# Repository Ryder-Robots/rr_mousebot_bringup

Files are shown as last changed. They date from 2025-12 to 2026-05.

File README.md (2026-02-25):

# RR Mousebot Bringup

ROS 2 launch package for an autonomous maze-solving robot designed to comply with IEEE Micromouse competition specifications.

## Project Overview

This package provides the core system bringup for a micromouse-compliant robot. While the robot does not compete in official competitions, it is designed to meet the technical specifications established by IEEE Micromouse competition rules for educational and developmental purposes.

The micromouse competition, first introduced by IEEE Spectrum in 1977, challenges participants to design and build autonomous robots capable of navigating from a start position to the center of an unknown maze in the shortest time possible (Christiansen, 1977). This project implements a ROS 2-based system that adheres to these specifications.

### IEEE Micromouse Competition Specifications

The robot is designed to comply with standard IEEE Micromouse specifications:

**Maze Specifications:**
- 16 x 16 grid of unit squares (each 18cm x 18cm)
- Wall height: 5 cm
- Wall thickness: 1.2 cm (±5% tolerance)
- Passageway width: 16.8 cm
- Total maze size: approximately 8 feet (2.44m) square
- Wall colors: white sides with red tops
- Floor: non-gloss black painted wood
(Micromouse Online, n.d.; IEEE Region 2, 2018)

**Robot Design Requirements:**
- Maximum dimensions: 25cm x 25cm (no height restriction)
- Must be self-contained (no remote control or external assistance)
- Cannot use combustion-based energy sources
- Must be fully autonomous
- Superstructure may extend above maze walls
(Micromouse Online, n.d.)

**Competition Rules (for reference):**
- 10-minute time limit for maze exploration and solving
- No ROM changes or program downloads after maze is revealed
- Each exit from starting square begins a new run
- Must reach destination square (center) for time to be recorded
- No communication with robot during competition runs
(IEEE Spectrum, 1979)

## Architecture

The `rr_mousebot.launch.py` launch file initializes a composable node container and a delayed lifecycle manager.

### Driver Container (`driver_container`)

Runs as `component_container_mt` (multi-threaded) under the `/driver` namespace.

**Active nodes:**

- **Motor Controller** (`rr_motor_controller::RrECU`, plugin: `rr_motor_controller::RrECU`):
  Lifecycle node (`nav2_util::LifecycleNode`) providing dual-motor PWM drive, quadrature encoder odometry, and odometry publishing.
  - GPIO transport: `rr_gpio_pi4b_pigpio_plugin::RrGpioPi4BPigpioPlugin` (Raspberry Pi 4B)
  - Encoder pins: `[9, 8]` (left, right); PWM pins: `[18, 19]`; Direction pins: `[23, 24]`
  - Wheel radius: 20 mm; wheel base: 70 mm; PPR: 8; PWM frequency: 1000 Hz
  - Encoder timeout: 500 000 µs
  - `use_intra_process_comms: True`

**Pending nodes (commented out, awaiting integration):**

- **UDP Receiver/Sender** (`udp_driver`): Network telemetry and debugging transport

### Lifecycle Manager

`nav2_lifecycle_manager` is launched with a **3-second `TimerAction` delay** to allow the driver container and its composable nodes to fully initialise before the manager attempts to discover them.

- `autostart: False` — lifecycle transitions are triggered manually (for debugging)
- `bond_timeout: 4.0 s` — heartbeat monitoring active once nodes reach the `active` state
- Manages: `/driver/motor_controller`

**Pending managed nodes (commented out):** `lidar_node`, `/driver/serial_bridge_node`, `/driver/udp_receiver_node`, `/driver/udp_sender_node`, `/sensor/rr_imu_action_node`

## Lifecycle Management Approach

The system employs ROS 2 lifecycle nodes to manage operational modes and optimize power consumption during different phases of maze solving:

### Operational Phases

1. **Explore Mode** (LIDAR Active)
   - System maps the 16x16 maze grid using 360° LIDAR
   - All sensors active for SLAM and navigation
   - Typical duration: 10-15 minutes
   - Power consumption: 3.7A (battery usage ~7-10%)
   - Returns to home position after complete exploration

2. **Planning Phase** (LIDAR Inactive)
   - LIDAR lifecycle transitioned to INACTIVE state to conserve power
   - Computes optimal path to center using A* or similar algorithm
   - Minimal power consumption during computation

3. **Run Mode** (LIDAR Inactive)
   - Executes pre-computed optimal path at maximum speed
   - LIDAR remains INACTIVE via lifecycle management
   - Power consumption: 3.4A (300mA savings per run)
   - Typical run duration: 30-60 seconds
   - Battery usage per run: ~0.3-0.6%

### Lifecycle Benefits

- **Power Efficiency**: Disabling LIDAR during runs saves ~300mA, enabling 150-175 runs per battery charge after initial exploration
- **Competition Ready**: Single battery supports 5-7 full competition attempts (explore + multiple runs) within 10-minute time limit
- **Resource Management**: Systematic activation/deactivation of sensor nodes based on operational requirements

## Battery Testing

Battery test results show the batteries are rated at 3.8V on charge, drawing approximately 3A during operation.

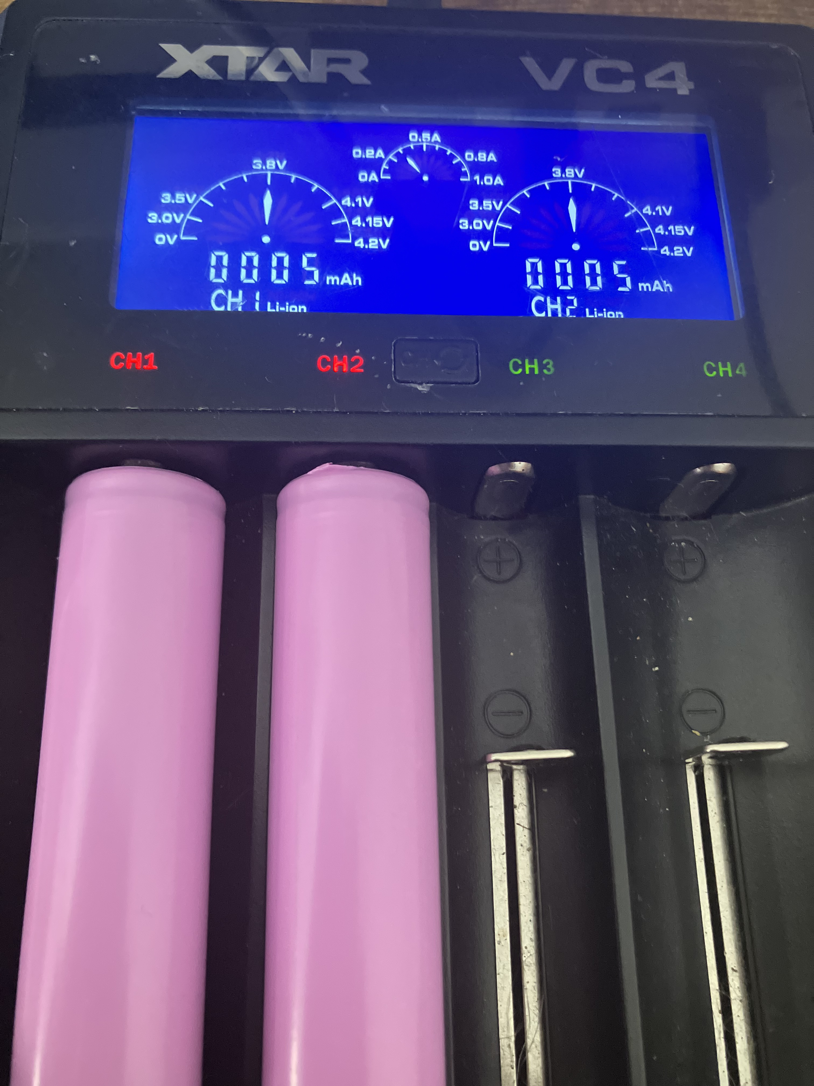
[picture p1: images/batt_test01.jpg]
Battery Test


## Schematic Directory

The [schematic/](schematic/) directory contains FreeCAD design files (.FCStd) for all mechanical and electrical components of the micromouse robot. These 3D CAD models are used for prototyping, assembly planning, and dimensional verification to ensure compliance with IEEE Micromouse specifications.

Key component designs include:
- Robot chassis and body assemblies
- Motor and encoder mountings
- Wheel designs (drive and caster wheels)
- Electronics mounting (Raspberry Pi, Arduino Nano, power circuits)
- Battery pack housing
- Power management circuits (buck converters)

The `stl/` subdirectory will be populated with STL files in future versions for 3D printing of custom components.

For detailed information about individual components, see [schematic/README.md](schematic/README.md).

For 3D printing instructions and assembly guidance, see [CONSTRUCTION.md](CONSTRUCTION.md).

## Dependencies and Installation

### ROS 2 System Requirements

This package requires ROS 2 and several dependency packages. Install the following components in order:

### Third-Party Dependencies

1. **Transport Drivers** (serial/UDP communication)
   ```bash
   # Install from https://github.com/ros-drivers/transport_drivers
   ```

2. **NAV2** (SLAM and navigation - under review)
   - Documentation: https://docs.nav2.org/tutorials/docs/navigation2_with_slam.html
   ```bash
   sudo apt install ros-${ROS_DISTRO}-nav2-bringup
   ```

3. **LD200 LIDAR Driver** (ldrobot-lidar-ros2)
   ```bash
   # Install dependencies
   sudo apt install libudev-dev

   # Clone into your ROS 2 workspace
   cd ~/ros2_ws/src
   git clone https://github.com/Myzhar/ldrobot-lidar-ros2.git

   # Apply ROS 2 Kilted patch (REQUIRED)
   cd ldrobot-lidar-ros2
   patch -p1 < ../rr_mousebot_bringup/scripts/ldrobot-lidar-ros2-kilted.patch

   # Build the package
   cd ~/ros2_ws
   rosdep install --from-paths src --ignore-src -r -y
   colcon build --symlink-install --cmake-args=-DCMAKE_BUILD_TYPE=Release --packages-select ldlidar ldlidar_component ldlidar_node
   ```
   - Native ROS 2 Lifecycle node with NAV2 lifecycle_manager integration
   - Driver for LD14P LIDAR sensor (part of D200 Developer Kit) - use `model: 'LDLiDAR_LD19'`
   - Device: `/dev/ttyAMA0` (Raspberry Pi hardware UART)
   - Topic: `/ldlidar_node/scan`
   - Patch file: [scripts/ldrobot-lidar-ros2-kilted.patch](scripts/ldrobot-lidar-ros2-kilted.patch)
   - See [CONSTRUCTION.md](CONSTRUCTION.md) for detailed setup and lifecycle management

### Ryder Robots Core Packages

Install the following Ryder Robots packages in order:

1. **Interfaces** (message/service definitions)
   ```bash
   # Clone and build: https://github.com/Ryder-Robots/rr_interfaces
   ```

2. **Common Base** (shared utilities and base classes)
   ```bash
   # Clone and build: https://github.com/Ryder-Robots/rr_common_base
   ```

3. **Common Plugins** (lifecycle and plugin components)
   ```bash
   # Clone and build: https://github.com/Ryder-Robots/rr_common_plugins
   ```

4. **Proto** (communication layer between Arduino and ROS 2)
   ```bash
   # Clone and build: https://github.com/Ryder-Robots/rr_proto
   ```

5. **Actions** (action server implementations)
   ```bash
   # Clone and build: https://github.com/Ryder-Robots/rr_imu_action
   # Note: Will be renamed to rr_actions and include all action implementations
   ```

### Optional Development Tools

- **Joystick Support** (recommended for testing and manual control)
  ```bash
  # Clone and build: https://github.com/Ryder-Robots/rr_joystick
  ```

### Arduino Firmware

Flash the Arduino Nano 33 BLE Sense Rev2 with the micromouse firmware:
- Repository: https://github.com/Ryder-Robots/rr_ble33_mousebot

### ROS 2 Installation

```bash
sudo apt update
sudo apt install ros-${ROS_DISTRO}-launch ros-${ROS_DISTRO}-launch-ros

# Source your ROS 2 workspace
source /opt/ros/${ROS_DISTRO}/setup.bash
source install/setup.bash
```

## Launch Command

```bash
ros2 launch rr_mousebot_bringup rr_mousebot.launch.py
```

## Manually configuring nodes

With `autostart: False`, the lifecycle manager starts but does not transition any nodes automatically. Use the service call or direct lifecycle commands:

```bash
# Trigger full startup (configure + activate all managed nodes) via lifecycle manager:
ros2 service call /lifecycle_manager_navigation/manage_nodes \
  nav2_msgs/srv/ManageLifecycleNodes "{command: 0}"

# Or drive the motor controller directly, one step at a time:
ros2 lifecycle get /driver/motor_controller
# unconfigured [1]
ros2 lifecycle set /driver/motor_controller configure
# Transitioning successful
ros2 lifecycle set /driver/motor_controller activate
# Transitioning successful
```

## Developer Notes

### Repository Architecture

This repository (`rr_mousebot_bringup`) contains all **mazebot-specific** components and configuration. All other repositories used by this project are designed to be **generic and reusable** across different robotic platforms and applications.

**Mazebot-Specific (this repository):**
- Launch configurations for the micromouse robot
- Hardware-specific parameter files
- Mazebot system integration and bringup logic
- Bill of Materials (BOM) and construction documentation
- Mechanical design files and schematics

**Generic/Reusable Repositories:**
- `rr_interfaces`: Common ROS 2 message and service definitions
- `rr_common_base`: Base lifecycle node implementations
- `rr_common_plugins`: Pluginlib-based navigation and control plugins
- `rr_proto`: Protocol buffer definitions for serial communication
- `rr_imu_action`: IMU-based action server implementations (being refactored to `rr_actions`)
- `rr_joystick`: Joystick/gamepad input handling
- `transport_drivers`: Serial and UDP communication drivers

These generic repositories can be used in other robotic projects, providing a modular foundation for ROS 2-based systems. Only `rr_mousebot_bringup` ties these components together into the specific mazebot application.

## References

Christiansen, D. (1977) 'The Amazing Micromouse Contest', *IEEE Spectrum*, 14(5). Available at: https://spectrum.ieee.org/the-amazing-micromouse-contest (Accessed: 13 December 2025).

IEEE Region 2 (2018) *Micromouse Competition Rules - IEEE R2 SAC 2018*. Available at: https://ewh.ieee.org/reg/2/sac-18/MicromouseRules.pdf (Accessed: 13 December 2025).

IEEE Spectrum (1979) 'The Amazing Micromouse Maze Contest', *IEEE Spectrum*, 16(6). Available at: https://spectrum.ieee.org/the-amazing-micromouse-contest (Accessed: 13 December 2025).

Micromouse Online (n.d.) *The Rules - Micromouse Book*. Available at: https://micromouseonline.com/micromouse-book/rules/ (Accessed: 13 December 2025).

Micromouse Online (n.d.) *Chassis Size - Micromouse Book*. Available at: https://micromouseonline.com/micromouse-book/the-chassis/chassis-size/ (Accessed: 13 December 2025).

## License

This project is licensed under the MIT License.

Copyright (c) 2025

Permission is hereby granted, free of charge, to any person obtaining a copy of this software and associated documentation files (the "Software"), to deal in the Software without restriction, including without limitation the rights to use, copy, modify, merge, publish, distribute, sublicense, and/or sell copies of the Software, and to permit persons to whom the Software is furnished to do so, subject to the following conditions:

The above copyright notice and this permission notice shall be included in all copies or substantial portions of the Software.

THE SOFTWARE IS PROVIDED "AS IS", WITHOUT WARRANTY OF ANY KIND, EXPRESS OR IMPLIED, INCLUDING BUT NOT LIMITED TO THE WARRANTIES OF MERCHANTABILITY, FITNESS FOR A PARTICULAR PURPOSE AND NONINFRINGEMENT. IN NO EVENT SHALL THE AUTHORS OR COPYRIGHT HOLDERS BE LIABLE FOR ANY CLAIM, DAMAGES OR OTHER LIABILITY, WHETHER IN AN ACTION OF CONTRACT, TORT OR OTHERWISE, ARISING FROM, OUT OF OR IN CONNECTION WITH THE SOFTWARE OR THE USE OR OTHER DEALINGS IN THE SOFTWARE.

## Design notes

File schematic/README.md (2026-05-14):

# Schematic Directory

This directory contains FreeCAD (.FCStd) design files for all mechanical and electrical components of the RR Mousebot. These 3D CAD models are used for design verification, assembly planning, and ensuring compliance with IEEE Micromouse competition specifications (maximum footprint: 25cm x 25cm).

## Directory Structure

```
schematic/
├── README.md           # This file
├── stl/                # STL and 3MF files for 3D printing
│   ├── body.stl        # Main chassis STL file
│   ├── body.3mf        # Main chassis 3MF file (recommended)
│   ├── drive_shaft.stl # Drive shaft STL file
│   └── drive_shaft.3mf # Drive shaft 3MF file (recommended)
└── *.FCStd             # FreeCAD design files
```

## STL Files

The `stl/` subdirectory contains 3D printable files exported from the FreeCAD designs. Files are provided in both STL and 3MF formats:

- **3MF Format** (recommended): Preserves units, scale, and metadata. Use with Elegoo Slicer for best results.
- **STL Format**: Universal format compatible with all slicers.

**Available Components:**
- `body.stl` / `body.3mf`: Main robot chassis (40% infill recommended)
- `drive_shaft.stl` / `drive_shaft.3mf`: Motor drive shaft (100% infill required for strength)

For detailed printing instructions, slicer settings, and post-processing guidance, see [CONSTRUCTION.md](../CONSTRUCTION.md).

## Component Design Files

### Main Assembly Files

#### [mazebot.FCStd](mazebot.FCStd)
Complete robot assembly integrating all mechanical and electrical components. This is the master assembly file that shows how all individual components fit together to form the complete micromouse robot.

#### [body.FCStd](body.FCStd)
Main chassis/body design for the robot. This component houses all electronics, motors, sensors, and power systems while maintaining compliance with the 25cm x 25cm maximum footprint requirement.

### Drive System Components

#### [hexwheel.FCStd](hexwheel.FCStd)
Hexagonal wheel design for the main drive wheels. The hex pattern may provide improved traction and maze navigation characteristics compared to standard circular wheels.

#### [caster_wheel.FCStd](caster_wheel.FCStd)
Caster wheel assembly providing passive support and stability. Typically mounted at the front or rear of the robot to create a stable three or four-point contact with the maze floor.

#### [tt_motor.FCStd](tt_motor.FCStd)
TT (Toy Train) motor model used for robot propulsion. These compact DC gear motors are commonly used in small robotics applications due to their favorable size-to-power ratio.

#### [motor_encoder.FCStd](motor_encoder.FCStd)
Optical encoder assembly for motor shaft position and velocity feedback. Encoders are essential for accurate odometry and closed-loop motor control during maze navigation.

### Electronics Mounting

#### [Raspberry Pi 4 Model B.STEP.FCStd](Raspberry%20Pi%204%20Model%20B.STEP.FCStd)
Raspberry Pi 4 Model B mounting design. The Pi serves as the main compute platform running ROS 2 and high-level navigation algorithms.

#### [nano-breakout.FCStd](nano-breakout.FCStd)
Arduino Nano breakout board design for interfacing with sensors and motor controllers. The Nano handles real-time sensor reading and motor control, communicating with the Raspberry Pi via serial connection.

#### [pi-rough.FCStd](pi-rough.FCStd)
Rough/preliminary mounting design for Raspberry Pi. This may be an earlier iteration or alternative mounting configuration for the Pi board.

### Power System

#### [battery_pack.FCStd](battery_pack.FCStd)
Battery pack housing and mounting design. Proper battery placement is critical for maintaining the robot's center of gravity and ensuring stable maze navigation.

#### [buck_circuit.FCStd](buck_circuit.FCStd)
Buck converter circuit mounting for power regulation. Buck converters step down the battery voltage to appropriate levels for different components (e.g., 5V for Raspberry Pi, 3.3V for sensors, motor voltage regulation).

## Bill of Materials (BOM)

This section lists the commercial off-the-shelf (COTS) components required to build the RR Mousebot. Prices are in AUD and include GST unless otherwise noted.

### Computing and Control

| Component | SKU | Quantity | Unit Price (inc GST) | Supplier | Notes |
|---|-----|---|---|---|---|
| Raspberry Pi 4 Model B 8GB | CE06974 | 1 | $145.00 | [Core Electronics](https://core-electronics.com.au/raspberry-pi-4-model-b-8gb.html) | Main compute platform for ROS 2 and navigation algorithms. 1.5GHz quad-core ARM Cortex-A72, Gigabit Ethernet, dual-band WiFi, Bluetooth 5.0. Typical current: ~3A at 5V |
| IO Expansion HAT for Raspberry Pi 4B/3B+ | DFR0566 | 1 | $17.50 | [Core Electronics](https://core-electronics.com.au/io-expansion-hat-for-raspberry-pi-4b-3b.html) | DFRobot GPIO expansion HAT. Provides UART, I²C, SPI, PWM, and digital I/O breakout terminals. 65×56mm. D200 LIDAR connects to UART terminals (T/R/5V/GND). Compatible with Gravity Series sensors |

### Sensors

| Component | SKU | Quantity | Unit Price (inc GST) | Supplier | Notes |
|---|-----|---|---|---|---|
| 360° Omni-directional Triangulation Lidar Dev Kit (8m range) | WS-24659 | 1 | $94.10 | [Core Electronics](https://core-electronics.com.au/360-omni-directional-triangulation-lidar-dev-kit-8m-range.html) | D200 Developer Kit with LD14P Lidar. 8m range, ±1.5% accuracy, 360° scanning, 4000Hz ranging frequency, UART @ 230400 baud (/dev/ttyAMA0 on Pi 4B/Pi 5). 5V DC, ≤300mA operating current. Includes UART to USB adapter. ROS 2 driver: https://github.com/Myzhar/ldrobot-lidar-ros2 (native lifecycle node, use model `LDLiDAR_LD19` for D200/LD14P). For SLAM, mapping, and obstacle detection |
| Adafruit BNO055 Absolute Orientation Sensor | CE04489 | 1 | $65.95 | [Core Electronics](https://core-electronics.com.au/adafruit-9-dof-absolute-orientation-imu-fusion-breakout-bno055.html) | Bosch BNO055 9-axis IMU. Provides fused absolute orientation (quaternion, Euler angles), angular velocity, and linear acceleration. I²C interface, address 0x28 (default) on /dev/i2c-1. 3.3V logic compatible. Onboard sensor fusion handles magnetometer calibration. Connects to DFR0566 HAT I²C terminals. ROS 2 driver: rr_bosch_lc_base |

### Motor Control

| Component | SKU | Quantity | Unit Price (inc GST) | Supplier | Notes |
|---|-----|---|---|---|---|
| Micro DC Geared Motor w/ Encoder - SJ01 6V 160RPM 120:1 | FIT0450 | 2 | $13.20 | [Core Electronics](https://core-electronics.com.au/micro-dc-geared-motor-w-encoder-sj01-6v-160rpm-120-1.html) | DFRobot micro DC motor with integrated Hall effect encoder. 120:1 gear ratio, 160 RPM @ 6V, stall torque 0.8 kg.cm. Operating voltage: 3-6V DC, no-load current 45mA, stall current 350mA. Encoder: 16 PPR (pulses per revolution of motor shaft), 1920 counts per revolution at output shaft (16 PPR × 120 gear ratio). Compact design: 25mm length (including output shaft). Includes pre-soldered 6-pin connector. Wiki: https://wiki.dfrobot.com/Micro_DC_Motor_with_Encoder-SJ01_SKU__FIT0450 |
| Makerverse Motor Driver 2 Channel | CE08038 | 1 | $7.20 | [Core Electronics](https://core-electronics.com.au/makerverse-motor-driver-2-channel.html) | Dual H-bridge motor driver. 1.6A continuous (2A peak), 3-16V input, compatible with 3.3V/5V logic. Includes thermal protection, reverse-polarity protection, and 5V regulator. 35x30mm with M3 mounting holes |

### Electrical Interface

| Component | SKU | Quantity | Unit Price (inc GST) | Supplier | Notes |
|---|-----|---|---|---|---|
| Logic Level Converter - Bidirectional | BOB-12009 | 1 | $2.95 | [Core Electronics](https://core-electronics.com.au/logic-level-converter-bidirectional.html) | SparkFun bidirectional 4-channel logic level converter. Shifts signals between 3.3V (Pi GPIO) and 5V (LIDAR, motor driver). Used in GPIO-controlled LIDAR power switch circuit |
| MOSFET Power Switch Module | CE09733 | 1 | $1.35 | [Core Electronics](https://core-electronics.com.au/mosfet-power-switch-module.html) | GPIO-controlled MOSFET power switch. **GPIO 24** controls 5V rail to LIDAR, held low during boot to prevent UART flooding on /dev/ttyAMA0. Software-controlled power-on in LIDAR node on_activate |

### Power System

| Component | SKU | Quantity | Unit Price (inc GST) | Supplier | Notes |
|---|-----|---|---|---|---|
| Samsung 18650 3500mAh 3.7V Rechargeable Battery | SB2632 | 2 | $33.50 | [Jaycar](https://www.jaycar.com.au/18650-samsung-3500mah-3-7v-18650-rechargeable-battery/p/SB2632) | Samsung INR18650-35E. 3500mAh capacity, 3.5A continuous/10A peak discharge. 7.4V nominal (2S configuration), 7000mAh total capacity provides ~51.8Wh energy storage |
| Dual 18650 Battery Holder | PH9207 | 1 | $6.95 | [Jaycar](https://www.jaycar.com.au/dual-18650-battery-holder/p/PH9207) | ABS plastic holder with 150mm leads. 75x39x20mm. Suitable for 2S (series) configuration providing 7.4V nominal output |
| DC-DC Adjustable Step-down Module 5A 75W | CE07271 | 1 | $2.55 | [Core Electronics](https://core-electronics.com.au/dc-dc-adjustable-step-down-module-5a-75w.html) | XL4015 buck converter. Input: 4-38V, Output: 1.25-36V adjustable, 5A max. 30-turn potentiometers for voltage/current adjustment. Provides 5V rail for Raspberry Pi and Lidar. Arduino Nano powered via USB from Raspberry Pi. 54x24x12mm with 3mm mounting holes |

### Mechanical Components

| Component | SKU | Quantity | Unit Price (inc GST) | Supplier | Notes |
|---|-----|---|---|---|---|
| Wheel - 65mm (Rubber Tire, Pair) | ROB-13259 | 1 | $9.55 | [Core Electronics](https://core-electronics.com.au/wheel-65mm-rubber-tire-pair.html) | Sparkfun basic wheels with black rubber tires. 65mm diameter, sold as pair (2 wheels). Compatible with DAGU right angle gear motors. For main drive wheels on differential drive robot |
| Supporting Swivel Caster Wheel - 1.3" Diameter | ADA2942 | 1 | $5.75 | [Core Electronics](https://core-electronics.com.au/supporting-swivel-caster-wheel-1-3-diameter.html) | 360° rotating support wheel. 32.4mm diameter, 42mm total height. Provides third-point stability for robot |
| Brass Heat-Set Inserts for Plastic - M3 x 3mm - 50 pack | ADA4256 | 1 | $11.65 | [Core Electronics](https://core-electronics.com.au/brass-heat-set-inserts-for-plastic-m3-x-3mm-50-pack.html) | M3 threaded brass inserts for 3D printed parts. 4.5mm OD, 3mm length. Heat-press installation with soldering iron. Provides strong, reusable threaded mounting points in plastic chassis |
| Makerverse M3 Mounting Kit | CE08342 | 1 | $3.25 | [Core Electronics](https://core-electronics.com.au/makerverse-m3-mounting-kit.html) | Hardware kit with 4x M3x12mm standoffs and 8x 6mm screws. For mounting electronics to chassis (up to 3mm material thickness) |

### BOM Notes

- **Total Component Cost** (listed items only): ~$422 AUD (excludes battery charger and 3D printed parts)

- **Power System Summary**: 2S Li-ion configuration (2x 18650 cells in series)
  - Nominal voltage: 7.4V (fresh), ~5.5V (under load/partially discharged)
  - Total capacity: 7000mAh (51.8Wh)
  - Continuous discharge: 7A (3.5A per cell)
  - Peak discharge: 20A (10A per cell, 5 seconds)
  - **Buck Converter Configuration** (adjust using flathead screwdriver):
    - Single converter: 5.5V → 5.0V rail for Raspberry Pi, LIDAR, and BNO055 (3.0A continuous load)
    - BNO055 IMU: Powered via DFR0566 HAT I²C rail (3.3V, included in Pi's power budget)
  - Motor power: Battery voltage (7.4V nominal, 5.5V under load) direct from battery through motor driver

- **Battery Charging**:
  - **IMPORTANT**: Battery cells must be removed from the holder and charged using an external 18650 Li-ion battery charger
  - Compatible chargers available from Core Electronics and Jaycar Australia
  - Do NOT attempt to charge batteries while installed in the robot
  - Recommended: 2S (7.4V) Li-ion smart charger with balance charging capability

- **Total Current Load Analysis** (at 5.5V battery voltage under load):
  - **5V Rail** (via Buck Converter):
    - Raspberry Pi 4: 3.0A (typical under load)
    - BNO055 IMU: ~0.01A (via DFR0566 HAT, included in Pi's budget)
    - LD14P Lidar: 0.3A (300mA operating current)
    - Motor Driver Control: 0.01A (minimal)
    - **Subtotal 5V Rail**: 3.36A (buck converter rated 5A, 67% utilization)
  - **Direct Battery (5.5V-7.4V)**:
    - Micro DC Motors with Encoders: 0.09A no-load (2x 45mA), 0.7A stall (2x 350mA max)
    - Typical operation (partial load): ~0.2A
    - **Subtotal Direct**: 0.2A typical
  - **System Total**: ~3.56A from battery typical (7A continuous capacity, 51% utilization)
  - **Runtime Estimate (Full System Active)**: 7000mAh / 3560mA ≈ 2.0 hours continuous operation

- **Operational Mode Battery Life Analysis**:
  - **Full System Runtime**:
    - Current draw: 3.56A typical (all systems active including LIDAR)
    - Runtime: 7000mAh / 3560mA ≈ **2.0 hours** (120 minutes) continuous operation
  - **Competition Scenario** (10-minute time limit):
    - Exploration phase: 10-15 minutes @ 3.56A = 593-890mAh (8-13% battery)
    - Speed runs with LIDAR inactive: @ 3.26A, minimal battery usage per run
    - **Result**: 5-7 full competition attempts (explore + multiple runs) per full battery charge
    - 360° LIDAR provides comprehensive SLAM and mapping with 8m range and ±1.5% accuracy

- **Motor System Summary**: 2x Micro DC Geared Motors with integrated Hall effect encoders for differential drive
  - Operating voltage: 3-6V DC (6V nominal, 5.5V typical under load)
  - Current draw: 45mA per motor no-load, ~100mA typical partial load, 350mA stall (per motor)
  - Speed: 160 RPM @ 6V (estimated ~145-160 RPM @ 5.5V under load)
  - Encoder: 16 PPR (motor shaft), 1920 counts per revolution at output shaft (16 PPR × 120:1 gear ratio)
  - Gear ratio: 120:1
  - Stall torque: 0.8 kg.cm
  - Motor driver provides 1.6A continuous capacity (>2x safety margin for typical operation, handles stall current)

- **Assembly Notes**:
  - Buck converter requires tuning with flathead screwdriver to achieve precise 5.0V output
  - Use multimeter to verify output voltage before connecting to Raspberry Pi
  - BNO055 IMU connects to DFR0566 HAT I²C terminals (SDA/SCL/3.3V/GND). Default I²C address: 0x28
  - Brass heat-set inserts (ADA4256) provide threaded mounting points in 3D printed chassis for M3 screws

- **Additional Components Required** (not listed above):
  - 18650 Li-ion battery charger (2S/7.4V compatible) - available from Core Electronics or Jaycar
  - Wiring, connectors, and miscellaneous hardware
  - 3D printed structural components (chassis, motor mounts, sensor brackets)
  - M3 screws (various lengths) for use with heat-set inserts

- **Quantity Discounts**: Available for most components when ordering 6+ or 10+ units
- **Availability**: Most items ship same business day; Lidar has lead time (ships Jan 6-9, 2025)
- **Suppliers**: Components sourced from Core Electronics Australia and Jaycar Australia

### Component Selection Rationale

- **Raspberry Pi 4 8GB**: Provides adequate computational power for ROS 2 nodes, SLAM algorithms, and path planning. 8GB RAM ensures headroom for development and debugging. 3A typical current draw fits within 5A buck converter capacity
- **BNO055 IMU**: Dedicated 9-axis orientation sensor with onboard sensor fusion. Provides quaternion output and linear acceleration directly — no fusion computation on the Pi. I²C interface integrates cleanly with the DFR0566 HAT and is natively supported by rr_bosch_lc_base as a ROS 2 lifecycle component. Eliminates the Arduino layer, simplifying the stack and reducing latency on the IMU data path
- **360° LIDAR (LD14P)**: 8m range exceeds maze dimensions (~2.5m), ±1.5% accuracy suitable for 18cm grid navigation. 360° scanning at 4000Hz ranging frequency enables comprehensive SLAM and obstacle detection. UART interface @ 230400 baud on /dev/ttyAMA0 (Raspberry Pi hardware UART, compatible with both Pi 4B and Pi 5). Low power consumption (≤300mA) with native ROS 2 Lifecycle node support via ldrobot-lidar-ros2 driver (https://github.com/Myzhar/ldrobot-lidar-ros2) - use `model: 'LDLiDAR_LD19'` for D200/LD14P sensor. Includes D200 developer kit with UART to USB adapter
- **Micro DC Geared Motors with Encoders (FIT0450)**: Ultra-compact design (25mm length) fits within tight micromouse footprint. 120:1 gear ratio provides excellent balance between speed (160 RPM @ 6V) and torque (0.8 kg.cm stall) for maze navigation. Integrated Hall effect encoder (16 PPR motor shaft = 1920 counts/rev at output shaft) eliminates need for separate encoder modules. Low power consumption: 45mA no-load, ~100mA typical operation. Pre-soldered 6-pin connector simplifies wiring. Comprehensive documentation: https://wiki.dfrobot.com/Micro_DC_Motor_with_Encoder-SJ01_SKU__FIT0450
- **Motor Driver**: 1.6A continuous current rating provides adequate safety margin (>8x for typical 200mA operation, >2x for 700mA stall current). Dual H-bridge enables independent bidirectional control for differential drive. Built-in 5V regulator, thermal protection, and compact form factor (35x30mm) with M3 mounting holes
- **Battery System**: Samsung 18650 cells chosen for high energy density (3500mAh), reliable performance, and proven track record. 2S configuration (7.4V nominal) provides appropriate voltage for motor driver input (3-16V range) and buck converter regulation. 51.8Wh total capacity supports ~2.0 hours continuous operation
- **Buck Converter**: Single XL4015 module provides reliable 5V regulation with 5A capacity exceeding system requirements (3.36A 5V rail + ~0.2A motors = 3.56A total load). Adjustable output voltage via 30-turn potentiometer enables precise 5.0V tuning with flathead screwdriver. Wide input range (4-38V) accommodates battery voltage variation during discharge. Arduino Nano powered via USB from Raspberry Pi eliminates need for separate 3.3V rail
- **Rubber Tire Wheels**: 65mm diameter wheels with black rubber tires provide good traction for differential drive robot. Sold as pair (2 wheels), compatible with DAGU right angle gear motors and suitable for micro DC motor mounting. Compact diameter fits within micromouse footprint constraints while providing adequate ground clearance
- **Heat-Set Inserts**: Brass M3 inserts provide strong, reusable threaded mounting points in 3D printed chassis. Superior to directly threading into plastic, allowing repeated assembly/disassembly without thread degradation. 50-pack provides sufficient quantity for entire robot assembly
- **Caster Wheel**: Small form factor (32.4mm) provides additional support point for stability during omnidirectional maneuvers
- **Mounting Hardware**: M3 standoffs provide secure mounting for motor driver and other electronics while maintaining proper spacing from chassis

## Electrical Circuits

### LIDAR Power Control — GPIO 24 via P-Channel MOSFET + NPN Inverter

The MOSFET Power Switch Module (CE09733) uses a **P-channel MOSFET**, which is active LOW on the SIG pin (SIG LOW = output ON, SIG HIGH = output OFF). Without an inverter, the floating GPIO at boot would leave SIG pulled low by default, powering the LIDAR immediately and flooding `/dev/ttyAMA0` before the ROS 2 driver is ready.

An NPN transistor inverter with a pull-up resistor solves this: the pull-up holds SIG HIGH at boot (LIDAR OFF), and driving GPIO 24 HIGH turns the NPN on, pulling SIG LOW (LIDAR ON).

**Logic table:**

| GPIO 24 | NPN | MOSFET SIG | LIDAR |
|---|-----|---|---|
| Float / LOW (boot) | OFF | HIGH (pull-up) | OFF ✅ |
| HIGH (software) | ON | LOW (pulled to GND) | ON ✅ |
| LOW (software) | OFF | HIGH (pull-up) | OFF ✅ |

**Components required:**

| Component | Value | Notes |
| --- | --- | --- |
| R1 | 1kΩ | Base resistor, GPIO 24 → NPN base |
| R2 | 10kΩ | Pull-up, 3.3V → MOSFET SIG |
| Q1 | NPN transistor | 2N2222, BC547, BC548, or S8050 |

**ASCII Schematic:**

```text
3.3V ─────────────────────────────────┐
                                      │
                                     R2
                                    10kΩ
                                      │
                                      ├──────────── MOSFET SIG
                                      │
Pi GPIO 24 ──── R1 ──── B            │
               1kΩ      │  Q1 (NPN)  │
                        C ───────────┘
                        E
                        │
GND ────────────────────┴──────────────────────────

MOSFET Power Switch Module (CE09733):
                                      
  5V Buck ──── [VIN │ P-CH MOSFET │ VOUT] ──── LIDAR 5V (red)
                    [     SIG     ]
                         │
                    (from NPN collector / R2 pull-up)

LIDAR GND ──── GND rail
LIDAR TX  ──── /dev/ttyAMA0 RX  (Pi GPIO 15)
LIDAR RX  ──── /dev/ttyAMA0 TX  (Pi GPIO 14)
```

**Physical wiring summary:**

```text
Pi header pin 18  (GPIO 24) ──── R1 (1kΩ) ──── Q1 base
Pi header pin 1   (3.3V)    ──── R2 (10kΩ) ─── Q1 collector ──── MOSFET SIG
Pi header pin 6   (GND)     ──── Q1 emitter
Buck 5V output              ──── MOSFET VIN
MOSFET VOUT                 ──── LIDAR 5V (red wire)
GND rail                    ──── LIDAR GND (black wire)
```

**Software control (lgpio):**

```python
import lgpio
h = lgpio.gpiochip_open(0)
lgpio.gpio_claim_output(h, 24)
lgpio.gpio_write(h, 24, 1)   # LIDAR ON
lgpio.gpio_write(h, 24, 0)   # LIDAR OFF
```

> **Note:** `gpiozero` on Ubuntu 24.04 requires `lgpio` as its backend. Install with `sudo apt install python3-lgpio`. Without it, GPIO commands succeed silently but produce no output.

---

## Design Workflow

1. **Individual Component Design**: Each mechanical and electrical component is designed in its own FreeCAD file with accurate dimensions and mounting features.

2. **Assembly Integration**: Components are imported and assembled in `mazebot.FCStd` to verify fit, clearances, and overall dimensions.

3. **Specification Verification**: The complete assembly is checked against IEEE Micromouse specifications:
   - Maximum footprint: 25cm x 25cm
   - Ground clearance compatible with 5cm maze walls
   - Center of gravity positioned for stable navigation

4. **STL Export** (future): Once designs are finalized, STL files will be exported to the `stl/` subdirectory for 3D printing.

## STL Subdirectory

The [stl/](stl/) subdirectory is reserved for STL (stereolithography) files that will be generated from the FreeCAD designs. These STL files will be:

- Optimized for 3D printing
- Properly oriented for minimal support material
- Scaled to actual dimensions
- Named to match their source FreeCAD files

**Status**: This directory will be populated in future versions as component designs are finalized and validated.

## Working with FreeCAD Files

To view or modify these designs:

1. Install FreeCAD (https://www.freecad.org/)
2. Open any `.FCStd` file in FreeCAD
3. Use the model tree to explore component features
4. Modify designs as needed for your specific hardware configuration

## Design Considerations

All component designs take into account:
- **IEEE Micromouse Compliance**: Maximum 25cm x 25cm footprint, no height restrictions
- **Maze Clearances**: 16.8cm passageway width, 5cm wall height
- **Component Integration**: Proper mounting points for electronics, sensors, and mechanical parts
- **Center of Gravity**: Low and centered for stable high-speed navigation
- **Serviceability**: Easy access to electronics and batteries for maintenance
- **Cable Routing**: Paths for power and data cables without interference

## File Naming Convention

- `*.FCStd`: FreeCAD native format files
- `*.STEP.FCStd`: FreeCAD files imported from STEP format (industry-standard CAD exchange format)
- `*.FCBak`: Automatic backup files created by FreeCAD (can be safely ignored)

## Version History

Component designs are version-controlled through Git. Refer to commit history for design evolution and changes. Major design iterations are documented in commit messages.

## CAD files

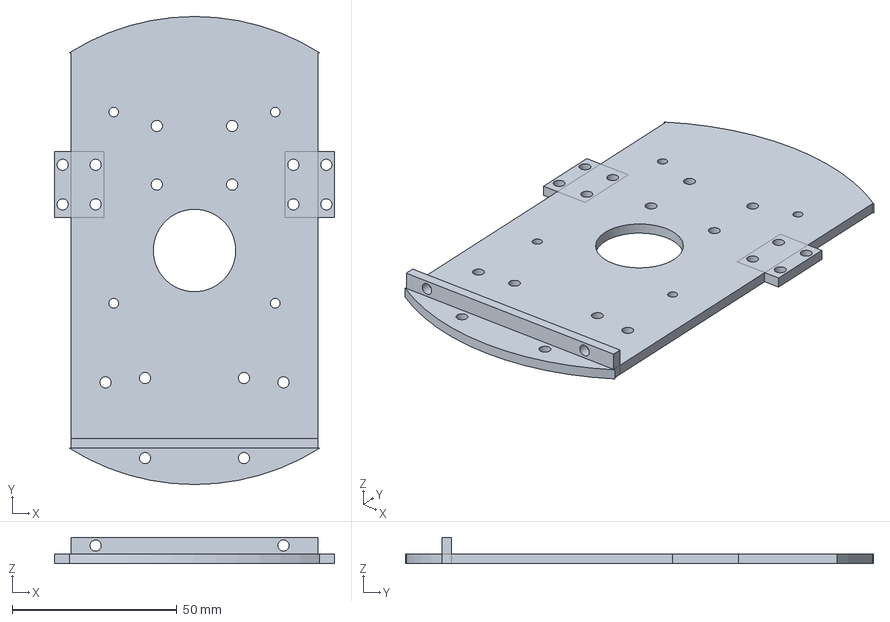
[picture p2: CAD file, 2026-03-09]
schematic/body.FCStd
85.0 x 142.0 x 8.00 mm

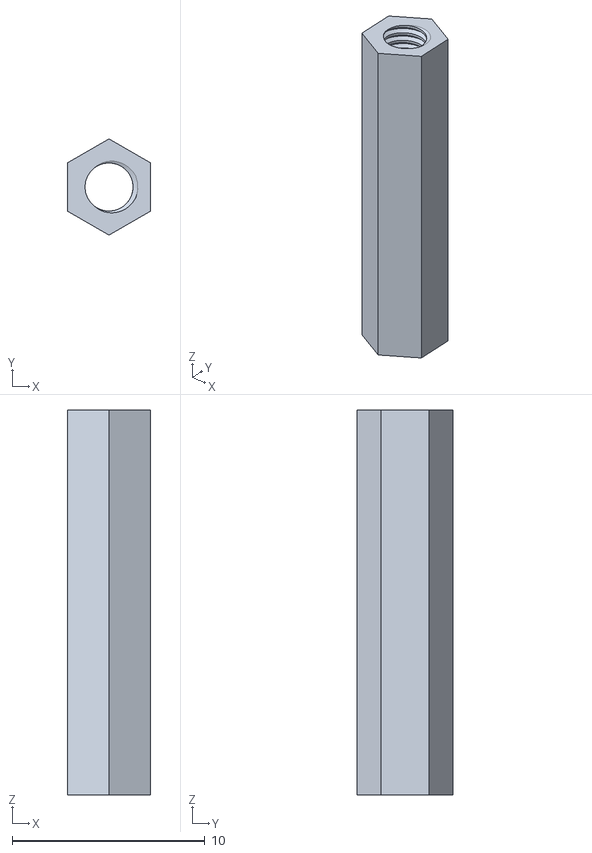
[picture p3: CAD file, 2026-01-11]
schematic/stl/m2.5_standoff.stl
4.33 x 5.00 x 20.0

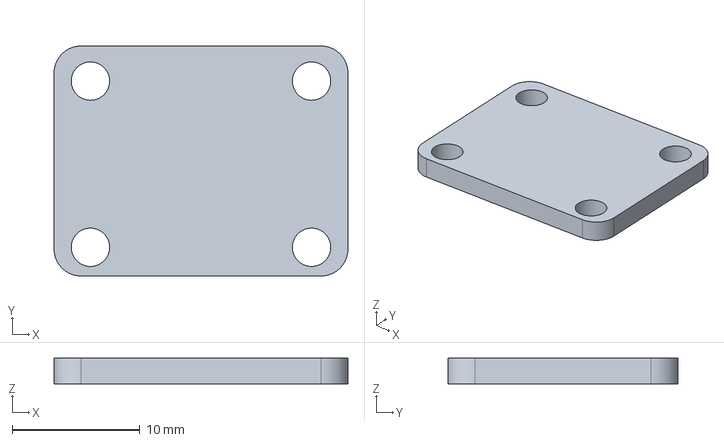
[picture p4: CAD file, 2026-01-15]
schematic/motor_encoder_bracket.FCStd
23.0 x 18.0 x 2.00 mm

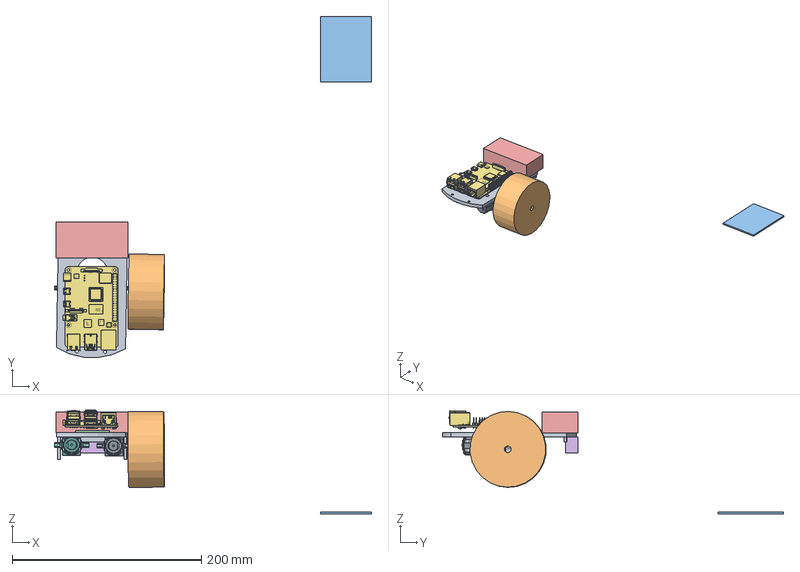
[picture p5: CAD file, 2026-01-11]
schematic/mazebot.FCStd
335.2 x 360.2 x 109.6 mm
body_Body_001
hexwheel_Body_002
nano-breakout_001
motor_encoder_001
battery_pack_001
buck_circuit_Body_001
Raspberry Pi 4 Model B.STEP_001
tt_motor_tt_motor001_001
tt_motor_tt_motor001_002

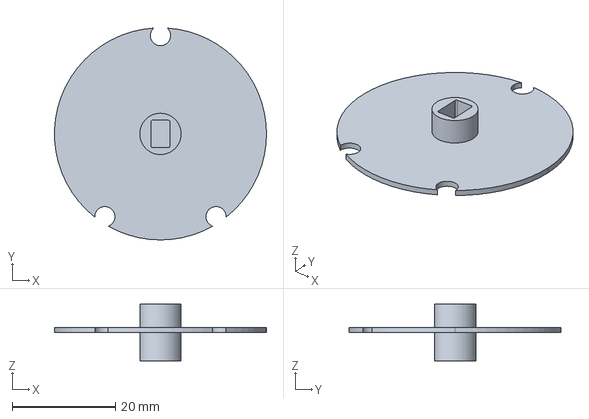
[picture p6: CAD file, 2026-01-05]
schematic/drive_shaft.FCStd
41.0 x 41.0 x 11.0 mm

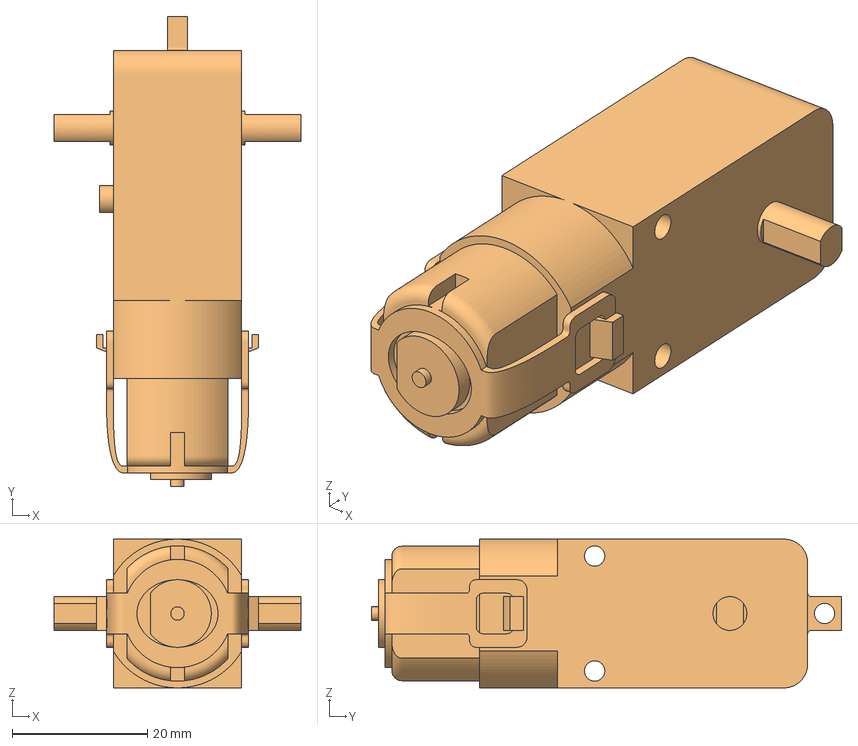
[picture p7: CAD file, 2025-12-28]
schematic/tt_motor.FCStd
36.5 x 69.5 x 22.0 mm
tt_motor001
tt_motor001 (Solid)
tt-motor

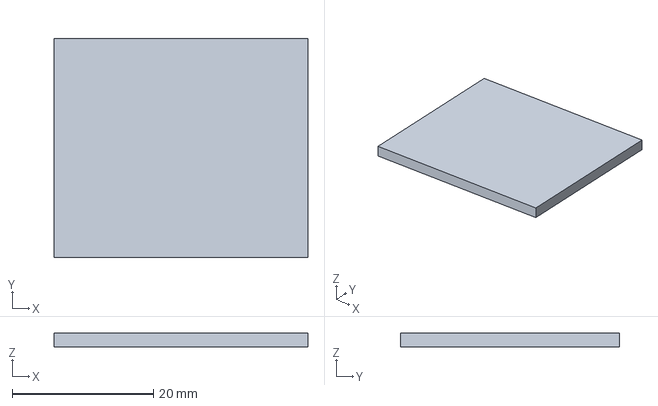
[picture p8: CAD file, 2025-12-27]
schematic/motor_encoder.FCStd
36.0 x 31.0 x 2.00 mm

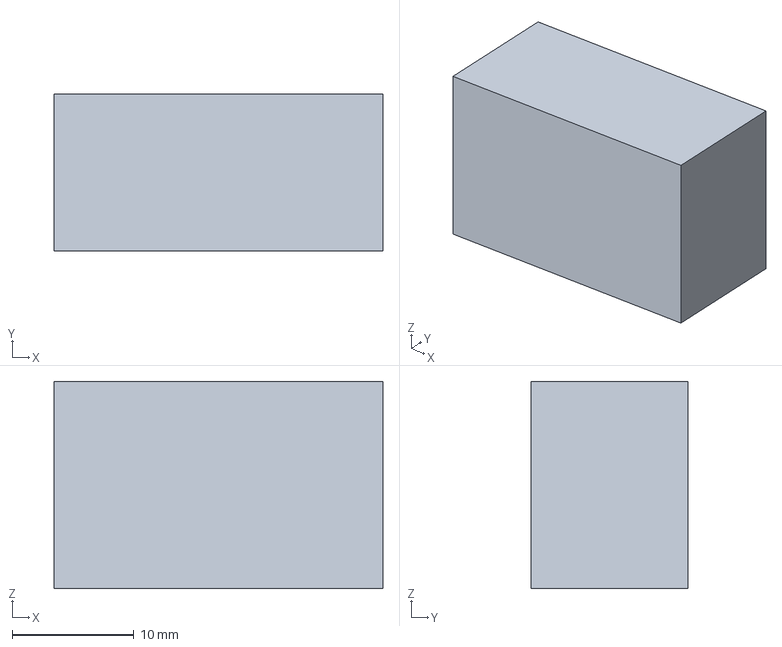
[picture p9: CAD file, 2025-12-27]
schematic/buck_circuit.FCStd
27.0 x 12.9 x 17.0 mm

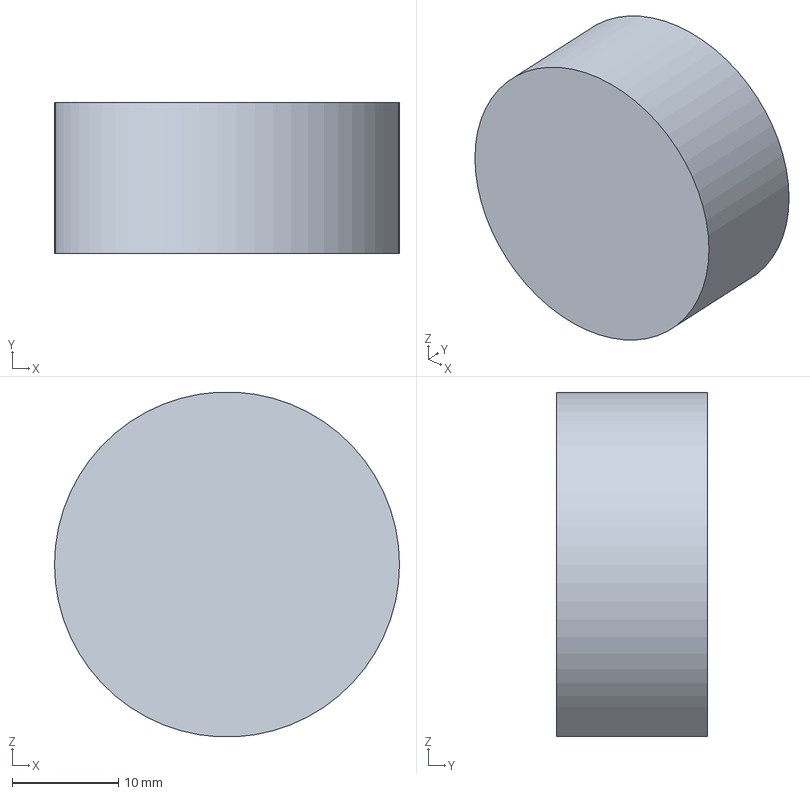
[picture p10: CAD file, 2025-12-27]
schematic/caster_wheel.FCStd
32.4 x 14.2 x 32.4 mm

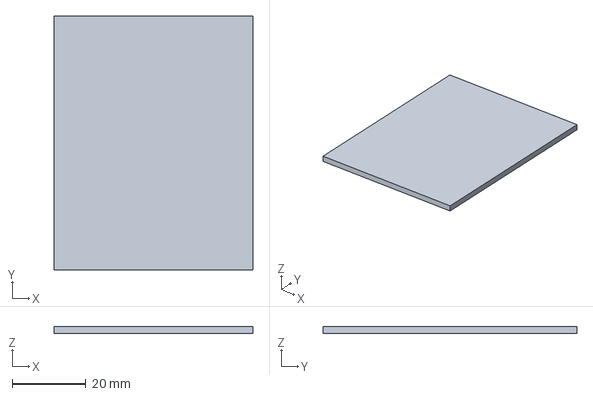
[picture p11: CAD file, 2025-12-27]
schematic/nano-breakout.FCStd
54.0 x 69.0 x 2.00 mm

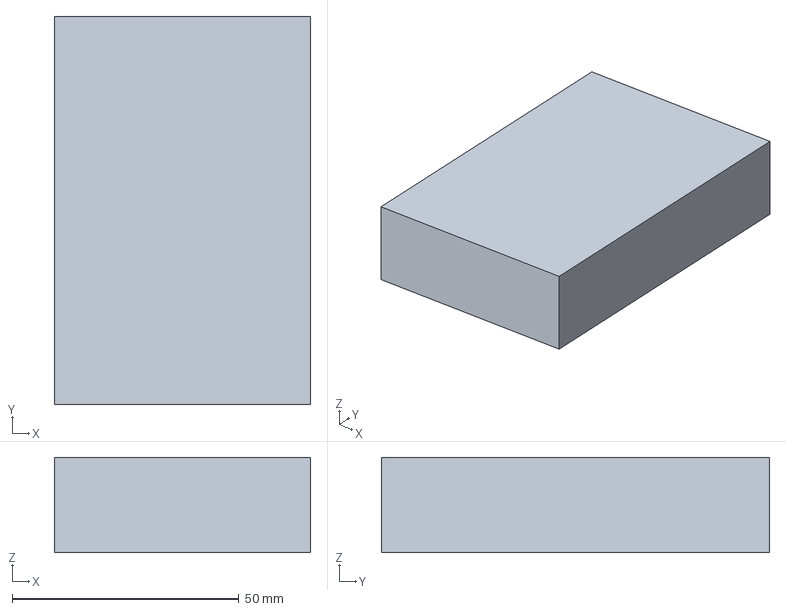
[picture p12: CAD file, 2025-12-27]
schematic/pi-rough.FCStd
56.5 x 85.6 x 21.0 mm

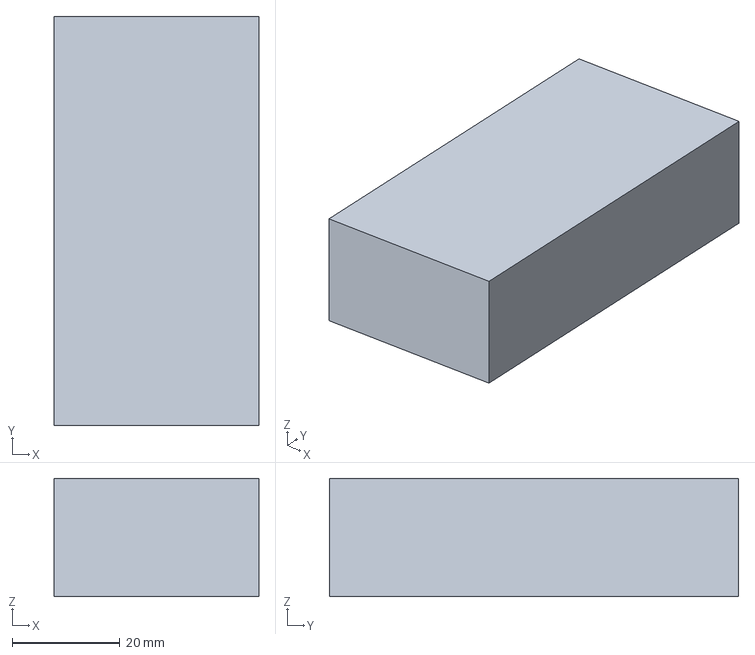
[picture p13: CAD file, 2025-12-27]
schematic/battery_pack.FCStd
38.0 x 76.0 x 22.0 mm

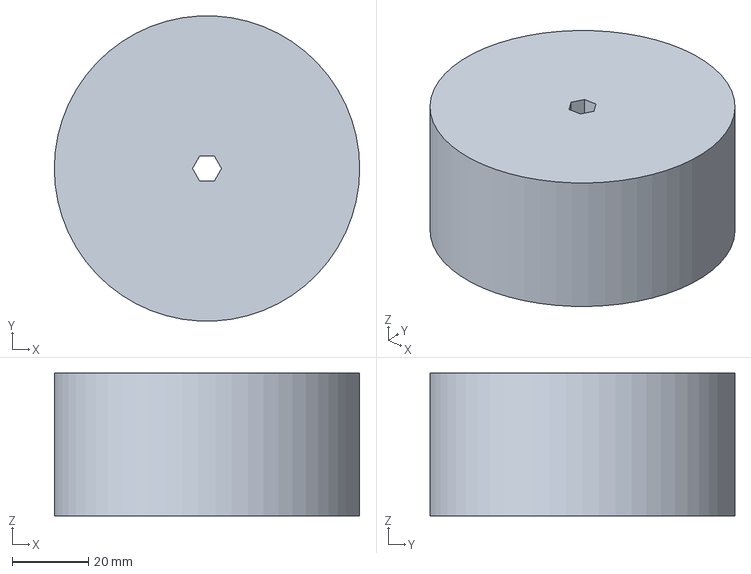
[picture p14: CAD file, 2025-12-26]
schematic/hexwheel.FCStd
80.0 x 79.9 x 37.4 mm

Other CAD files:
schematic/m2.5.FCStd
schematic/Raspberry Pi 4 Model B.STEP.FCStd
schematic/body.stl
schematic/stl/body.3mf
schematic/stl/body.stl
schematic/stl/motor_encoder_bracket.3mf
schematic/stl/motor_encoder_bracket.stl

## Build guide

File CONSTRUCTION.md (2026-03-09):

# RR Mousebot Construction Guide

This guide provides detailed instructions for 3D printing and assembling the RR Mousebot chassis and mechanical components.

## STL Files

All 3D printable files are located in the `schematic/stl/` directory. Files are provided in both STL and 3MF formats:

**Available Files:**

- `body.stl` / `body.3mf`: Main robot chassis
- `drive_shaft.stl` / `drive_shaft.3mf`: Motor drive shaft

**Format Recommendations:**

- **3MF Format** (recommended): Use with Elegoo Slicer for preserved scale, units, and metadata
- **STL Format**: Universal compatibility with any slicer software

See [schematic/README.md](schematic/README.md) for complete list of available components.

---

## 3D Printing Configuration

### Equipment

- **Printer**: Elegoo Centauri Carbon (enclosed)
- **Filament Dryer**: Creality Filament Heater
- **Recommended Slicer**: Elegoo Slicer (or compatible)

### Material Selection

- **Prototyping**: PETG (for quick iteration and testing)
- **Final Build**: ABS (for superior strength and durability)

This guide focuses on PETG settings for prototyping. ABS settings will be added for final production builds.

---

## PETG Printing Configuration

### Filament Preparation

PETG is hygroscopic and must be thoroughly dried before printing to prevent moisture-related defects (bubbles, stringing, weak layer adhesion).

#### Creality Filament Heater Settings

**Pre-Loading Drying (New or Exposed Filament)**:

- Temperature: 65-70°C
- Duration: 4-6 hours
- Purpose: Remove absorbed moisture before loading into printer

**Quick Dry (Recently Exposed Filament)**:

- Temperature: 60°C
- Duration: 2-4 hours
- Purpose: Light moisture removal without risking filament softening
- Note: Avoid higher temperatures to prevent PETG deformation

**Storage Mode (Active Storage)**:

- Temperature: 50-55°C
- Duration: Indefinite (while filament is loaded)
- Purpose: Maintain dry state during extended print sessions

**Best Practice**: Pre-dry at 65°C for 4-6 hours, then maintain at 50-55°C during printing.

---

### Elegoo Centauri Carbon Printer Settings

Configure these settings in your slicer (Elegoo Slicer recommended) for optimal PETG prints on the Centauri Carbon.

#### Temperature Settings

| Parameter | Temperature | Notes |
| --- | --- | --- |
| Nozzle (Standard) | 230-250°C | Start at 240°C for initial calibration |
| Nozzle (First Layer) | 245°C | Higher temp improves bed adhesion |
| Heated Bed | 70-80°C | Preheat for 10 minutes before printing |
| Chamber (with Creality mod) | 40-50°C | Enclosed chamber maintains stable temperature |

**Temperature Tuning**:

- If stringing occurs: Reduce nozzle temp by 5°C increments
- If layer adhesion is weak: Increase nozzle temp by 5°C increments
- If warping occurs: Increase bed temp to 80°C

#### Print Speed Settings

| Parameter | Speed | Notes |
| --- | --- | --- |
| First Layer | 20-30 mm/s | Slow for optimal bed adhesion |
| Perimeters | 30-40 mm/s | Balance quality and speed |
| Infill | 40-50 mm/s | Can be faster than perimeters |
| Travel Moves | 150-200 mm/s | Fast non-printing moves |
| Retraction Speed | 40 mm/s | Prevents stringing |

#### Cooling Settings

| Parameter | Setting | Notes |
| --- | --- | --- |
| Part Cooling Fan | 10-30% | PETG requires minimal cooling |
| First Layer Fan | 0% | No cooling for first layer adhesion |
| Bridging Fan | 40-50% | Increase for overhangs/bridges |

**Cooling Notes**:

- PETG is sensitive to over-cooling which causes warping and poor layer adhesion
- Use minimum cooling for structural parts
- Increase cooling slightly for detailed features or overhangs

#### Retraction Settings

| Parameter | Setting | Notes |
| --- | --- | --- |
| Retraction Distance | 0.5-1.0 mm | Start at 0.8mm for direct drive |
| Retraction Speed | 40 mm/s | Prevents nozzle clogging |
| Z-Hop on Retraction | 0.2 mm | Optional, reduces surface artifacts |

**Retraction Tuning**:

- Increase distance if stringing persists (up to 1.5mm max)
- Decrease if you observe clogging or under-extrusion after travels

#### Layer and Extrusion Settings

| Parameter | Setting | Notes |
| --- | --- | --- |
| Layer Height | 0.2 mm | Standard quality (0.12-0.28mm range) |
| First Layer Height | 0.2 mm | Match standard layer height |
| Line Width | 0.4 mm | Match nozzle diameter |
| Infill Density | 20-40% | 20% for prototypes, 40% for structural parts |
| Infill Pattern | Gyroid or Grid | Gyroid for strength, Grid for speed |
| Wall Count | 3-4 | Minimum 3 for strength |
| Top/Bottom Layers | 4-5 | Ensures solid surfaces |

#### Bed Adhesion

| Parameter | Setting | Notes |
| --- | --- | --- |
| Bed Surface | PEI Sheet or Glass with Glue Stick | Clean before each print |
| First Layer Flow | 105-110% | Slight over-extrusion for adhesion |
| Brim | Optional (5-10mm) | Use for small contact areas |
| Supports | Auto-generate | Enable for overhangs >50° |

**Bed Preparation**:

1. Clean PEI sheet with isopropyl alcohol before each print
2. For glass bed: Apply thin layer of glue stick or hairspray
3. Allow bed to preheat for 10 minutes to ensure even temperature distribution

---

### Elegoo Slicer Profile Template

Create a custom PETG profile in Elegoo Slicer with these settings:

```text
Filament: PETG
Nozzle: 240°C (first layer 245°C)
Bed: 75°C
Chamber: 45°C
Speed: 40 mm/s (first layer 25 mm/s)
Cooling: 20% (first layer 0%)
Retraction: 0.8mm @ 40mm/s
Layer Height: 0.2mm
Walls: 4
Infill: 30% Gyroid
Supports: Auto (>50° threshold)
```

---

## Print Quality Troubleshooting

### Common PETG Issues and Solutions

| Issue | Cause | Solution |
| --- | --- | --- |
| Stringing | Excessive moisture or temp too high | Dry filament at 65°C for 6 hours; reduce nozzle temp by 5°C |
| Warping | Insufficient bed temp or over-cooling | Increase bed temp to 80°C; reduce part cooling to 10% |
| Poor layer adhesion | Nozzle temp too low or wet filament | Increase nozzle temp to 245°C; dry filament thoroughly |
| Bubbling/Popping | Moisture in filament | Dry filament at 65-70°C for 6 hours minimum |
| Excessive stringing | Retraction settings incorrect | Increase retraction distance to 1.0mm; enable Z-hop 0.2mm |
| First layer not sticking | Bed not level or temp too low | Re-level bed; increase bed temp to 80°C; clean bed surface |

---

## Component-Specific Print Settings

### Chassis and Body Parts

**Files**: `body.stl` / `body.3mf`

**Priority**: Strength and durability

```text
Infill: 40% Gyroid
Walls: 4
Top/Bottom Layers: 5
Layer Height: 0.2mm
Supports: Yes (auto-generated)
```

### Motor Mounts and Brackets

**Priority**: High strength, heat resistance

```text
Infill: 50% Gyroid or Honeycomb
Walls: 5
Top/Bottom Layers: 6
Layer Height: 0.16mm (higher resolution)
Supports: Yes (manual placement recommended)
```

### Wheel Hubs and Drive Components

**Files**: `drive_shaft.stl` / `drive_shaft.3mf`

**Priority**: Maximum strength and precision

```text
Infill: 100% Solid
Walls: 4
Top/Bottom Layers: 5
Layer Height: 0.12mm (fine detail)
Supports: Minimal (design for printability)
```

**Note**: Drive shafts must be printed at 100% infill to withstand motor torque and prevent mechanical failure during operation.

### Electronic Enclosures

**Priority**: Fit tolerance and assembly ease

```text
Infill: 20% Grid (lightweight)
Walls: 3
Top/Bottom Layers: 4
Layer Height: 0.2mm
Supports: Minimal (use overhangs <45°)
```

---

## Heat-Set Insert Installation

After printing parts with heat-set insert holes:

1. **Preheat Soldering Iron**: 200-220°C for PETG
2. **Align Insert**: Position brass insert (M3 x 3mm) perpendicular to hole
3. **Apply Steady Pressure**: Press insert slowly and evenly until flush with surface
4. **Cool**: Allow part to cool for 2-3 minutes before removing iron
5. **Verify**: Test thread with M3 screw to ensure proper engagement

**Caution**: Do not exceed 250°C as PETG may deform around insert hole.

---

## Post-Processing

### Support Removal

- Remove support material carefully using flush cutters
- Sand contact points with 220-grit sandpaper for smooth finish
- Clean with compressed air to remove debris

### Surface Finishing (Optional)

- Light sanding with 400-grit sandpaper for smoother surfaces
- Acetone vapor smoothing NOT recommended for PETG (use for ABS only)
- **IMPORTANT**: Wear non-static gloves during sanding to prevent contaminants from adhering to components

### Component Washing

After support removal and sanding are complete, all printed components should be thoroughly cleaned:

1. **Wash Process**:
   - Use lukewarm water with a light detergent (dish soap works well)
   - Gently scrub all surfaces to remove dust, oils, and particulates from printing and post-processing
   - Pay special attention to areas where supports were removed
   - Rinse thoroughly with clean water to remove all detergent residue

2. **Drying**:
   - Allow components to air dry completely in a clean, dust-free environment
   - Can use compressed air to accelerate drying in hard-to-reach areas
   - Ensure components are **thoroughly dried** before proceeding to assembly
   - Typical drying time: 2-4 hours (longer for complex geometries with internal cavities)

3. **Safety Notes**:
   - Wear non-static gloves throughout the washing and drying process to prevent contamination
   - Do NOT use hot water as it may deform PETG parts
   - Avoid harsh chemicals or solvents that could weaken the plastic

### Assembly Preparation

- Test fit all components before final assembly
- Verify heat-set inserts are properly seated
- Clean all contact surfaces with isopropyl alcohol if additional cleaning is needed

---

## Electronic Assembly

### Nano I/O Shield (DFR0012) Configuration

The Nano I/O Shield provides convenient connectivity for the Arduino Nano 33 BLE Sense Rev2, but requires specific configuration to prevent damage and ensure proper operation.

#### **CRITICAL: Nano Switch Setting**

Set the shield's Nano switch to **V4** position for Arduino Nano 33 BLE Sense Rev2 compatibility.

- **Purpose**: Routes I²C signals (A4/SDA, A5/SCL) correctly to the Rev2's integrated I²C pins
- **Consequence of incorrect setting**: I²C communication failures with all connected sensors (LIDAR, encoders, etc.)

#### **CRITICAL: GND Jumper Cap Removal**

**⚠️ WARNING: FAILURE TO REMOVE THE JUMPER CAP CAN PERMANENTLY DAMAGE THE ARDUINO NANO 33 BLE SENSE REV2 ⚠️**

When using external 5V power to the shield (from buck converter) while the Arduino Nano is powered via USB from the Raspberry Pi, you **MUST** remove the GND jumper cap from the Servo power selection port.

**Jumper Cap Configuration**:

1. **Default Position**: The jumper cap is installed on the Servo power selection port connecting to USB (ships from factory in this position)
2. **Required Action**: **REMOVE** the jumper cap entirely or move it to a safe position away from the Servo power selection port
3. **Do NOT**: Leave the jumper cap connecting USB power to external servo power rail

**Why This Matters (Jumper Logic)**:

- The jumper cap in default position connects the Nano's USB 5V supply to the shield's servo/peripheral power rail
- When external 5V (from buck converter) is supplied to the shield's servo terminals, the jumper creates a parallel connection between two power sources
- This causes **voltage back-feeding** from the external regulator into the Arduino Nano's USB power circuit
- Back-feeding can exceed the USB power circuit's safe operating limits, resulting in permanent component damage
- **Removing the jumper isolates** the two power domains:
  - Arduino Nano powered via USB from Raspberry Pi (communication + microcontroller power)
  - Shield peripherals (servos, sensors) powered via external 5V from buck converter

**Power Configuration Summary**:
- **Arduino Nano 33 BLE Sense Rev2**: Powered via USB from Raspberry Pi (5V @ ~50mA)
- **Nano I/O Shield peripherals**: Powered via external 5V from buck converter connected to servo terminal blocks
- **Jumper Cap**: **REMOVED** to isolate the two power domains

### Power Distribution: Buck Converter to Nano I/O Shield

The buck converter provides 5V power to the Nano I/O Shield's servo/peripheral terminals for sensors and other connected devices.

**Wiring Instructions**:

| Buck Converter Terminal | Nano I/O Shield Terminal | Wire Gauge | Description |
| --- | --- | --- | --- |
| 5V Output (Positive) | Servo Terminal VCC/+ | 22-20 AWG | Regulated 5V power for peripherals |
| GND (Negative) | Servo Terminal GND/- | 22-20 AWG | Common ground return |

**Connection Notes**:

1. Use the servo terminal blocks on the Nano I/O Shield (typically labeled S1, S2, etc.)
2. Connect buck converter 5V output to the **VCC/+** pin of any servo terminal
3. Connect buck converter GND to the **GND/-** pin of the same servo terminal
4. All servo terminal power pins are internally connected, so connection to any terminal block is acceptable
5. Verify 5.0V output with multimeter before connecting to shield
6. **Ensure jumper cap is removed** as described above before applying external power

**Current Budget**:

- Total load on shield 5V rail: Sensors, encoders, and peripherals (see BOM for detailed current analysis)
- Buck converter capacity: 5A continuous (adequate margin for all shield loads)

### URM09 Ultrasonic Sensor Connection

The URM09 Ultrasonic Sensor connects to the Arduino Nano 33 BLE Sense Rev2 via the Nano I/O Shield's I²C panel.

**Connection Instructions**:

1. **Locate I²C Panel**: Find the I²C connector panel on the Nano I/O Shield (DFR0012)
2. **Connect Jumper Wires**: The URM09 includes jumper wires with the following color coding:
   - **Black**: GND (Ground)
   - **Red**: VCC (Power, 3.3-5.5V)
   - **Blue**: SCL (I²C Clock)
   - **Green**: SDA (I²C Data)

   Connect each wire to the corresponding pin on the Nano I/O Shield's I²C panel
3. **Power**: Sensor draws 20mA from the I²C connection (powered by shield's external 5V supply)
4. **I²C Address**: Default address is 0x11 (configurable via software if needed)

**Mounting Notes**:

- Mount sensor facing forward (same direction as Arduino Nano mini USB port)
- Ensure clear line of sight for ultrasonic waves (no obstructions within 2-500cm range)
- Sensor provides 1cm resolution with 1% accuracy for maze wall detection

For I²C communication protocol and Arduino firmware integration, see the [rr_ble33_mousebot repository](https://github.com/Ryder-Robots/rr_ble33_mousebot).

### D200 LIDAR Connection to Raspberry Pi

The 360° Omni-directional Triangulation LIDAR (D200 Developer Kit with LD14P) connects to the Raspberry Pi 4 Model B via UART for ROS 2 SLAM and mapping.

**Important Notes**:

- **DFR0566 GPIO Expansion HAT (Optional)**: The DFRobot GPIO Expansion HAT (DFR0566) provides convenient UART breakout terminals for connecting the D200 LIDAR. However, **the DFR0566 is optional** - the D200 can be connected directly to the Raspberry Pi GPIO pins. Both connection methods have been tested and verified to work. The DFR0566 simplifies wiring with screw terminals but direct GPIO connection is also fully supported.
- **⚠️ WIRING CAVEAT**: The cable supplied with the D200 LIDAR **does not use standard wire colors**. Always verify wire functions against the official documentation: [LD14P Development Manual (PDF)](https://files.waveshare.com/upload/9/99/LD14P_Development_Manual.pdf). Do not rely solely on wire colors - verify each wire's function before connecting.

#### Hardware Connection

**Connection Method 1: Using DFR0566 GPIO Expansion HAT (Recommended for Convenience)**

**D200 to Raspberry Pi 4B Wiring via DFR0566 UART Terminals**:

| D200 Wire Color | Function | DFR0566 Terminal | Raspberry Pi 4B GPIO | Physical Pin | Description |
|---|---|---|---|---|---|
| Red | RX (Receive) | UART T | GPIO14 TXD | Pin 8 | D200 receives data from Pi |
| Green | TX (Transmit) | UART R | GPIO15 RXD | Pin 10 | D200 transmits data to Pi |
| White | GND (Ground) | GND | Ground | Pin 6, 9, or 14 | Common ground |
| Black | VCC (Power) | 5V | 5V Power Rail | Pin 2 or 4 | 5V power supply |

**GPIO Pinout Reference**: [Raspberry Pi GPIO Documentation](https://www.raspberrypi.com/documentation/computers/raspberry-pi.html#gpio)

**⚠️ CRITICAL**: Wire colors shown above are based on common D200 cable configurations. **Always verify wire functions using a multimeter or by consulting the [LD14P Development Manual](https://files.waveshare.com/upload/9/99/LD14P_Development_Manual.pdf)** before making connections. The cable supplied with your device may use different colors.

**Connection Explanation**:

- The D200's standard 4-wire cable aligns perfectly with Pi UART polarity through DFR0566's passthrough UART terminals
- **T terminal** (Transmit from Pi perspective) = Pi TX (GPIO14) → D200 RX (Red wire)
- **R terminal** (Receive from Pi perspective) = Pi RX (GPIO15) → D200 TX (Green wire)
- This configuration ensures proper bidirectional UART communication at 230400 baud

#### Physical Assembly

1. **Stack DFR0566 HAT on Raspberry Pi 4B**:
   - Align the 40-pin GPIO header
   - Press firmly to ensure full contact
   - Secure with standoffs if provided

2. **Connect D200 Cable to DFR0566 Terminals**:
   - Connect D200 **Red wire** (RX) to DFR0566 **UART T** terminal
   - Connect D200 **Green wire** (TX) to DFR0566 **UART R** terminal
   - Connect D200 **White wire** (GND) to DFR0566 **GND** terminal
   - Connect D200 **Black wire** (VCC) to DFR0566 **5V** terminal

3. **Verify Connections**:
   - Double-check wire colors match terminal assignments
   - Ensure wires are securely fastened in screw terminals
   - Confirm no loose connections that could cause intermittent operation

**Connection Method 2: Direct GPIO Connection (No DFR0566 Required)**

If you choose not to use the DFR0566 HAT, you can connect the D200 LIDAR directly to the Raspberry Pi 4B GPIO header. **This method has been tested and verified to work.**

**D200 to Raspberry Pi 4B Direct GPIO Wiring**:

| D200 Wire Color | Function | Raspberry Pi 4B GPIO | Physical Pin | Description |
|---|---|---|---|---|
| Red | RX (Receive) | GPIO14 TXD | Pin 8 | D200 receives data from Pi |
| Green | TX (Transmit) | GPIO15 RXD | Pin 10 | D200 transmits data to Pi |
| White | GND (Ground) | Ground | Pin 6, 9, or 14 | Common ground |
| Black | VCC (Power) | 5V Power Rail | Pin 2 or 4 | 5V power supply |

**GPIO Pinout Reference**: [Raspberry Pi GPIO Documentation](https://www.raspberrypi.com/documentation/computers/raspberry-pi.html#gpio)

**⚠️ CRITICAL**: Wire colors shown above are based on common D200 cable configurations. **Always verify wire functions using a multimeter or by consulting the [LD14P Development Manual](https://files.waveshare.com/upload/9/99/LD14P_Development_Manual.pdf)** before making connections.

**Direct Connection Assembly**:

1. **Prepare GPIO Connections**:
   - Use female Dupont jumper wires to connect D200 cable to Raspberry Pi GPIO pins
   - Alternatively, solder wires directly to D200 cable and use female Dupont connectors for Pi GPIO

2. **Make Connections**:
   - Connect D200 **Red wire** (RX) to Pi **GPIO14 TXD** (Physical Pin 8)
   - Connect D200 **Green wire** (TX) to Pi **GPIO15 RXD** (Physical Pin 10)
   - Connect D200 **White wire** (GND) to Pi **Ground** (Physical Pin 6, 9, or 14)
   - Connect D200 **Black wire** (VCC) to Pi **5V** (Physical Pin 2 or 4)

3. **Verify Connections**:
   - Double-check wire colors match GPIO pin assignments
   - Ensure secure connections at GPIO header
   - Confirm no loose connections that could cause intermittent operation
   - **IMPORTANT**: Verify correct GPIO pins before applying power to prevent damage

#### Raspberry Pi UART Configuration

The Raspberry Pi's hardware UART must be enabled and configured for the D200 LIDAR.

**Enable UART via raspi-config**:

1. Open terminal on Raspberry Pi
2. Run configuration utility:

   ```bash
   sudo raspi-config
   ```

3. Navigate to: **Interface Options** → **Serial Port**
4. Configure as follows:
   - **"Would you like a login shell to be accessible over serial?"** → Select **NO**
     - This disables the console login shell on the serial port
   - **"Would you like the serial port hardware to be enabled?"** → Select **YES**
     - This enables the UART hardware interface
5. Exit raspi-config and reboot:

   ```bash
   sudo reboot
   ```

**Verification**:

After reboot, verify UART is enabled:

```bash
ls -l /dev/serial0
```

Expected output should show `/dev/serial0` linked to `/dev/ttyAMA0` (hardware UART).

**Test LIDAR Wiring and Communication**:

To verify the D200 LIDAR is properly connected and transmitting data:

```bash
stty -F /dev/ttyAMA0 230400 && cat /dev/ttyAMA0
```

**Expected Result**: You should see binary data streaming from the LIDAR. The output will appear as scrambled characters (this is normal - it's raw LIDAR scan data). Press `Ctrl+C` to stop.

**If no data appears**:

- Verify power connection (Black wire to 5V)
- Check ground connection (White wire to GND)
- Verify TX/RX connections are correct (Green to UART R, Red to UART T)
- Confirm LIDAR is spinning (motor should be audible/visible)
- Double-check wire functions against the [LD14P Development Manual](https://files.waveshare.com/upload/9/99/LD14P_Development_Manual.pdf)

#### UART Hardware Testing on Raspberry Pi 5 (Development Note)

**Note**: When testing the D200 LIDAR hardware on Raspberry Pi 5 for development purposes, UART configuration can be difficult to troubleshoot. While GPIO headers remain the same as other Raspberry Pi models (see [Raspberry Pi GPIO Documentation](https://www.raspberrypi.com/documentation/computers/raspberry-pi.html#gpio)), it's recommended to verify UART functionality before connecting the LIDAR.

**UART Loopback Test Procedure**:

1. **Create Hardware Loopback**:
   - Place a jumper wire between **Pin 8 (GPIO14 TXD)** and **Pin 10 (GPIO15 RXD)**
   - This creates a loopback where transmitted data is immediately received back

2. **Install minicom** (if not already installed):

   ```bash
   sudo apt-get install minicom
   ```

3. **Launch minicom**:

   ```bash
   minicom -b 115200 -D /dev/ttyAMA0
   ```

4. **Disable Echo**:
   - Press `Ctrl+A` then `E` to toggle local echo OFF
   - This prevents double-character display (local echo + loopback echo)

5. **Test Serial Communication**:
   - Type any random characters on the keyboard
   - **Expected Result**: Characters should be echoed back in the terminal
   - If characters appear, UART hardware is working correctly
   - If no characters appear, UART may not be properly enabled or configured

6. **Exit minicom**:
   - Press `Ctrl+A` then `X` to exit
   - Remove the jumper wire before connecting the D200 LIDAR

**Troubleshooting**:

- If loopback test fails, verify UART is enabled in `raspi-config` (Interface Options → Serial Port)
- Check `/boot/firmware/config.txt` for `enable_uart=1`
- Ensure no other service is using `/dev/ttyAMA0` (check with `sudo lsof | grep ttyAMA0`)
- On Raspberry Pi 5, UART configuration may differ slightly from Pi 4 - consult official documentation if issues persist

#### GPIO Testing with WiringPi

WiringPi provides a convenient command-line tool for testing and verifying GPIO pin configurations on Raspberry Pi.

**WiringPi Repository**: https://github.com/WiringPi/WiringPi

**Installation**:

1. **Install GPIO library dependency**:

   ```bash
   sudo apt install liblgpio-dev
   ```

2. **Create temporary directory and download**:

   ```bash
   mkdir -p ${HOME}/tmp
   cd ${HOME}/tmp
   wget https://github.com/WiringPi/WiringPi/releases/download/3.16/wiringpi_3.16_arm64.deb
   chmod 755 ${HOME}/tmp
   ```

3. **Verify download integrity**:

   ```bash
   sha256sum ./wiringpi_3.16_arm64.deb
   ```

   **Expected hash**: `db494454383e72b9af5ca1617a77e571da1ceb4f50279f7efe45bb4c3c863ff6`

   ⚠️ **Do not proceed if the hash does not match** - re-download or check for updated release.

4. **Install the package**:

   ```bash
   sudo apt install ./wiringpi_3.16_arm64.deb
   ```

5. **Add user to GPIO group** (required for non-root GPIO access):

   ```bash
   sudo usermod -a -G gpio $USER
   ```

6. **Set GPIO memory device permissions**:

   ```bash
   sudo chgrp gpio /dev/gpiomem
   ```

   This allows users in the `gpio` group to access GPIO memory directly.

   Log out and log back in for group membership to take effect.

**Test GPIO Configuration**:

After installation, verify all GPIO pins are accessible and correctly configured:

```bash
gpio readall
```

This displays a table showing all GPIO pins, their modes (IN/OUT/ALT), and current values. Use this to:

- Verify UART pins (GPIO14/GPIO15) are in ALT mode for serial communication
- Confirm GPIO pins are available for encoder inputs
- Debug pin configuration issues before connecting hardware

#### ROS 2 Integration

**UART Device Path**: `/dev/serial0`
**Baud Rate**: 230400

The `ldlidar_ros2` lifecycle node will automatically detect and configure the D200 LIDAR on `/dev/serial0` at 230400 baud for ROS 2 `/scan` topic publishing.

**Node Configuration** (in launch file):
```python
'serial_port': '/dev/serial0',
'serial_baudrate': 230400,
'topic_name': 'scan',
'lidar_frame': 'base_laser',
'range_threshold': 0.005  # 5mm minimum range
```

**Setup Confirmation**:

1. Hardware: DFR0566 stacked on Pi 4B, D200 cable connected to UART/5V/GND terminals exactly as specified
2. Software: UART enabled via `raspi-config` (login shell disabled, hardware enabled)
3. ROS 2: `ldlidar_ros2` lifecycle node configured for `/dev/serial0` at 230400 baud
4. Result: Automatic `/scan` topic publishing for SLAM and navigation

For ROS 2 LIDAR driver configuration and lifecycle management, see the main launch file in this repository.

#### LD200 LIDAR ROS 2 Software Setup

The LD200 LIDAR (LD14P sensor) requires the `ldrobot-lidar-ros2` driver package for ROS 2 integration. This driver provides native ROS 2 Lifecycle node support with NAV2 lifecycle manager integration.

**Driver Repository**: https://github.com/Myzhar/ldrobot-lidar-ros2

**Installation Instructions**:

1. **Install dependencies**:

   ```bash
   sudo apt install libudev-dev
   ```

2. **Clone the ldrobot-lidar-ros2 repository** into your ROS 2 workspace:

   ```bash
   cd ~/ros2_ws/src
   git clone https://github.com/Myzhar/ldrobot-lidar-ros2.git
   ```

3. **Apply ROS 2 Kilted Patch** (REQUIRED for Kilted):

   The upstream driver does not yet support ROS 2 Kilted. Apply the patch from this repository:

   ```bash
   cd ~/ros2_ws/src/ldrobot-lidar-ros2
   patch -p1 < ../rr_mousebot_bringup/scripts/ldrobot-lidar-ros2-kilted.patch
   ```

   **Patch Contents** (for reference):
   - Adds `kilted` to the supported ROS 2 distributions list
   - Adds `-DFOUND_KILTED` preprocessor definition for Kilted builds
   - Sets default serial port to `/dev/ttyAMA0` (Raspberry Pi hardware UART)

   **Verify patch applied successfully**:

   ```bash
   git diff --stat
   ```

   Expected output shows modifications to `ldlidar_component/CMakeLists.txt`, `ldlidar_node/CMakeLists.txt`, and `ldlidar_node/params/ldlidar.yaml`.

4. **Install ROS dependencies**:

   ```bash
   cd ~/ros2_ws
   rosdep install --from-paths src --ignore-src -r -y
   ```

5. **Build the package**:

   ```bash
   colcon build --symlink-install --cmake-args=-DCMAKE_BUILD_TYPE=Release --packages-select ldlidar ldlidar_component ldlidar_node
   ```

6. **Source the workspace**:

   ```bash
   source ~/ros2_ws/install/setup.bash
   ```

**Device Configuration**:

The LD200 LIDAR connects via UART and appears as `/dev/ttyAMA0` on both Raspberry Pi 4B and Raspberry Pi 5 (hardware UART).

**Verify the device**:

```bash
ls -l /dev/ttyAMA0
```

**Test LIDAR Communication**:

```bash
stty -F /dev/ttyAMA0 230400 && cat /dev/ttyAMA0
```

Expected result: Binary data stream (appears as scrambled characters). Press `Ctrl+C` to stop.

**D200/LD14P Model Configuration**:

The D200 Developer Kit contains the LD14P sensor, which uses the same protocol as the LD19. Configure the driver to use `LDLiDAR_LD19` model.

The patch sets `/dev/ttyAMA0` as the default serial port. If you need to customize other parameters, edit `ldlidar_node/params/ldlidar.yaml`:

```yaml
/**:
  ros__parameters:
    general:
      debug_mode: false

    comm:
      serial_port: '/dev/ttyAMA0'  # Raspberry Pi hardware UART
      baudrate: 230400
      timeout_msec: 1000

    lidar:
      model: 'LDLiDAR_LD19'  # Use LD19 for D200/LD14P (same protocol)
      rot_verse: 'CCW'       # Counter-clockwise (ROS standard)
      units: 'M'             # Meters (ROS standard)
      frame_id: 'ldlidar_link'
      bins: 455              # Fixed scan size for SLAM Toolbox compatibility
      range_min: 0.03
      range_max: 15.0
```

**Launch the LIDAR Driver**:

The ldrobot-lidar-ros2 package is based on ROS 2 Lifecycle architecture. The node starts in `UNCONFIGURED` state.

**Option 1: Manual Lifecycle Control**

Start the node:
```bash
ros2 run ldlidar_node ldlidar_node
```

Configure the node (establishes connection):
```bash
ros2 lifecycle set /ldlidar_node configure
```

Activate the node (starts publishing scans):
```bash
ros2 lifecycle set /ldlidar_node activate
```

**Option 2: Launch with YAML Parameters**

```bash
ros2 launch ldlidar_node ldlidar.launch.py
```

This starts the node with parameters from `ldlidar.yaml` and a `robot_state_publisher` that provides the static TF transform [`ldlidar_base` → `ldlidar_link`].

**Option 3: Launch with NAV2 Lifecycle Manager (Recommended)**

```bash
ros2 launch ldlidar_node ldlidar_with_mgr.launch.py
```

This automatically handles lifecycle transitions using the NAV2 `lifecycle_manager`.

**Verify LIDAR Data**:

Check that the LIDAR is publishing scan data:
```bash
ros2 topic echo /ldlidar_node/scan
```

Expected output: `sensor_msgs/LaserScan` messages with range data.

**Lifecycle Node Integration** (for power management):

The `ldrobot-lidar-ros2` driver is a native ROS 2 Lifecycle node, ideal for the power-saving strategy described in the main README (LIDAR inactive during speed runs).

**Lifecycle Management**:

1. **Check node lifecycle state**:
   ```bash
   ros2 lifecycle get /ldlidar_node
   ```

2. **Configure the node** (establish connection):
   ```bash
   ros2 lifecycle set /ldlidar_node configure
   ```

3. **Activate the node** (start LIDAR scanning):
   ```bash
   ros2 lifecycle set /ldlidar_node activate
   ```

4. **Deactivate the node** (stop LIDAR scanning, save power):
   ```bash
   ros2 lifecycle set /ldlidar_node deactivate
   ```

5. **Cleanup the node**:
   ```bash
   ros2 lifecycle set /ldlidar_node cleanup
   ```

6. **Shutdown the node**:
   ```bash
   ros2 lifecycle set /ldlidar_node shutdown
   ```

**Power Management Strategy**:
- **Explore Mode**: Activate LIDAR for SLAM and mapping
- **Planning Phase**: Deactivate LIDAR to conserve power (~300mA savings)
- **Run Mode**: Keep LIDAR deactivated during speed runs

This lifecycle approach enables the 150-175 runs per battery charge as described in the README's "Lifecycle Management Approach" section.

**Integration with System Launch File**:

For integration into the main `rr_mousebot.launch.py` launch file, refer to the ldrobot-lidar-ros2 repository documentation and your existing lifecycle node patterns in the launch file.

**Troubleshooting**:

- **Permission denied on /dev/ttyAMA0**: Add your user to the `dialout` group:
  ```bash
  sudo usermod -aG dialout $USER
  ```
  Log out and log back in for changes to take effect.

- **Transitioning failed on configure**: Check node logs for connection errors. Verify UART is enabled and LIDAR is powered (motor should be spinning).

- **Invalid lidar.model error**: Ensure `model: 'LDLiDAR_LD19'` is set in `ldlidar.yaml`. The D200/LD14P uses the LD19 protocol. Valid models are: `LDLiDAR_LD06`, `LDLiDAR_LD19`, `LDLiDAR_STL27L`.

- **No data on /ldlidar_node/scan topic**: Ensure node is in `ACTIVE` state. Check `ros2 lifecycle get /ldlidar_node`.

- **Device not found**: Confirm `/dev/ttyAMA0` exists and UART hardware is enabled (see "Raspberry Pi UART Configuration" section above).

- **Build fails with "ROS2 kilted is not officially supported"**: Ensure the Kilted patch has been applied. Re-run the patch command from step 3.

### Motor and Encoder Wiring

The Micro DC Geared Motors with integrated encoders (FIT0450) connect to both the Makerverse Motor Driver 2 Channel (CE08038) for motor control and to the Arduino Nano 33 BLE Sense Rev2 via the Nano I/O Shield (DFR0012) for encoder signals.

**Motor Documentation**: [DFRobot Micro DC Motor with Encoder-SJ01 Wiki](https://wiki.dfrobot.com/Micro_DC_Motor_with_Encoder-SJ01_SKU__FIT0450)

**Arduino Pinout Reference**: [Arduino Nano 33 BLE Sense Rev2 Pinout](https://docs.arduino.cc/resources/pinouts/ABX00031-full-pinout.pdf)

**Connection Notes**:
- DIR pins control motor rotation direction (HIGH/LOW)
- PWM pins control motor speed (0-255 duty cycle)
- All control signals are 3.3V logic compatible with Arduino Nano 33 BLE Sense Rev2

#### Motor A (Left Motor) Complete Wiring

Each motor has a 6-pin connector with the following connections:

| Motor Pin | Pin Name | Connected Device | Device Pin | Description |
|---|---|---|---|---|
| 1 | Motor Power + | Motor Driver (MKRVRS) | A+ | Motor power supply +, 3-7.5V (Rated 6V) |
| 2 | Motor Power - | Motor Driver (MKRVRS) | A- | Motor power supply - |
| 3 | Encoder A Phase | Nano I/O Shield | D8 | Encoder A phase output (digital) |
| 4 | Encoder B Phase | Nano I/O Shield | D9 | Encoder B phase output (digital) |
| 5 | Encoder VCC | Nano I/O Shield | VCC (5V) | Encoder power supply (5V) |
| 6 | Encoder GND | Nano I/O Shield | GND | Encoder ground |

**Encoder Specifications**:
- 16 PPR (pulses per revolution) at motor shaft
- 1920 counts per revolution at output shaft (16 PPR × 120:1 gear ratio)
- Hall effect sensor type
- Operating voltage: 5V DC

#### Motor B (Right Motor) Complete Wiring

| Motor Pin | Pin Name | Connected Device | Device Pin | Description |
|---|---|---|---|---|
| 1 | Motor Power + | Motor Driver (MKRVRS) | B+ | Motor power supply +, 3-7.5V (Rated 6V) |
| 2 | Motor Power - | Motor Driver (MKRVRS) | B- | Motor power supply - |
| 3 | Encoder A Phase | Nano I/O Shield | D10 | Encoder A phase output (digital) |
| 4 | Encoder B Phase | Nano I/O Shield | D11 | Encoder B phase output (digital) |
| 5 | Encoder VCC | Nano I/O Shield | VCC (5V) | Encoder power supply (5V) |
| 6 | Encoder GND | Nano I/O Shield | GND | Encoder ground |

#### Motor Rotation Direction

**Motor A Clockwise Rotation**:
- Condition: Motor Power + (Pin 1) is positive via A+, Motor Power - (Pin 2) is negative via A-, DIR-A is HIGH
- Result: Motor shaft rotates clockwise when viewed from the shaft end
- Use case: Forward motion for left wheel

**Motor A Counter-Clockwise Rotation**:
- Condition: DIR-A is LOW (polarity reversal via H-bridge)
- Result: Motor shaft rotates counter-clockwise
- Use case: Reverse motion for left wheel

**Motor B Clockwise Rotation**:
- Condition: Motor Power + (Pin 1) is positive via B+, Motor Power - (Pin 2) is negative via B-, DIR-B is HIGH
- Result: Motor shaft rotates clockwise when viewed from the shaft end
- Use case: Forward motion for right wheel

**Motor B Counter-Clockwise Rotation**:
- Condition: DIR-B is LOW (polarity reversal via H-bridge)
- Result: Motor shaft rotates counter-clockwise
- Use case: Reverse motion for right wheel

#### Encoder Reading

**Quadrature Encoder Operation**:
- Each motor has two encoder output signals: A Phase and B Phase
- The phase relationship between A and B determines rotation direction
- Forward rotation: A leads B by 90° (A changes state before B)
- Reverse rotation: B leads A by 90° (B changes state before A)
- Each rising and falling edge can be counted for 4x resolution: 16 PPR × 4 = 64 counts/rev (motor shaft), 7680 counts/rev (output shaft)

**Encoder Pin Connections Summary**:
- Motor A: D8 (A Phase), D9 (B Phase)
- Motor B: D10 (A Phase), D11 (B Phase)
- Both encoders powered by 5V from Nano I/O Shield

#### Wiring Best Practices

1. **Color Coding Consistency**:
   - Use white wires for all DIR (direction) signals
   - Use yellow wires for all PWM (speed) signals
   - Motors include pre-soldered 6-pin connectors

2. **Wire Management**:
   - Secure wires with cable ties to prevent interference with moving parts
   - Keep motor power wires (pins 1-2) separated from encoder signal wires (pins 3-6) to minimize electrical noise
   - Route encoder signals away from motor driver PWM signals
   - Use shielded cable for encoder signals if noise issues occur

3. **Testing Sequence**:
   - Test encoder signals first before connecting motor power
   - Verify encoder counts increment/decrement correctly with manual rotation
   - Test each motor individually before full assembly
   - Verify rotation direction matches expected behavior
   - Confirm PWM speed control operates smoothly across 0-255 range
   - Verify encoder direction detection (A leads B vs B leads A)

4. **Safety**:
   - Double-check polarity before applying power
   - Ensure motor driver heat sink has adequate clearance for cooling
   - Monitor motor driver temperature during initial testing
   - Verify encoder VCC is connected to 5V (not 3.3V) for proper operation

For motor control and encoder reading firmware implementation, see the [rr_ble33_mousebot repository](https://github.com/Ryder-Robots/rr_ble33_mousebot).

### BNO055 IMU — Technical Documentation

#### Optional Pins and Their Purpose

**P0 / P1** (not P50 — likely mislabelled on your board)

Boot mode selection pins for the BNO055 chip. Both should be pulled low (GND) for normal I2C operation. The Adafruit breakout has onboard pull-down resistors so they're handled automatically — no wiring needed.

**PS1**

Protocol select pin — together with PS0 selects I2C or SPI mode. For I2C, PS1 should be low. Again, Adafruit handles this onboard — no wiring needed.

**INT**

Interrupt output pin — the BNO055 can assert this pin when certain events occur (motion detected, data ready, etc.). For basic IMU fusion output you don't need it — just poll via I2C at your node's update rate. Only wire it if you want interrupt-driven data acquisition, which adds complexity for marginal benefit given you're reading at a fixed rate anyway.

**ADR**

I2C address select. Pull low → address 0x28, pull high → address 0x29. Useful if you have two BNO055s on the same bus. The Adafruit breakout defaults to 0x28 with ADR unconnected. Only wire it if you have an address conflict.

#### Summary — Required Connections

For this use case you only need:

| Pin | Description |
|-----|---|
| VIN | Power supply |
| GND | Ground |
| SDA | I2C data |
| SCL | I2C clock |
| RST | Optional — for software reset |

INT and ADR can be left unconnected.

#### Verifying BNO055 I2C Connection

**Note**: This step should be performed on your development box only. Once the software is installed and wiring is confirmed correct, it is not required for normal operation.

Requires `i2c-tools` to be installed:

```bash
sudo apt install i2c-tools
```

Run the I2C bus scan to verify the BNO055 is detected:

```bash
i2cdetect -y 1
```

Expected output with BNO055 at default address 0x28:

```text
     0  1  2  3  4  5  6  7  8  9  a  b  c  d  e  f
00:                         -- -- -- -- -- -- -- --
10: -- -- -- -- -- -- -- -- -- -- -- -- -- -- -- --
20: -- -- -- -- -- -- -- -- 28 -- -- -- -- -- -- --
30: -- -- -- -- -- -- -- -- -- -- -- -- -- -- -- --
40: -- -- -- -- -- -- -- -- -- -- -- -- -- -- -- --
50: -- -- -- -- -- -- -- -- -- -- -- -- -- -- -- --
60: -- -- -- -- -- -- -- -- -- -- -- -- -- -- -- --
70: -- -- -- -- -- -- -- --
```

The `28` at position 0x28 confirms the BNO055 is correctly wired and responding on the I2C bus. If nothing appears, check SDA/SCL connections and ensure the sensor is powered.

---

## Material Storage

**PETG Storage Recommendations**:

- Store in airtight container with desiccant packets
- Ideal humidity: <15% RH
- If stored >1 week, re-dry at 60°C for 2-4 hours before use
- Keep away from direct sunlight and heat sources

---

## ABS Configuration (Future)

ABS settings for final production builds will be documented here once prototyping phase is complete. ABS requires:

- Higher temperatures (230-260°C nozzle, 100-110°C bed)
- Enclosed chamber (mandatory)
- Reduced cooling
- Acetone vapor smoothing capability

---

## Safety Notes

- **Ventilation**: Ensure adequate ventilation when printing PETG
- **Temperature**: Allow heated bed and nozzle to cool before handling
- **Fire Safety**: Never leave printer unattended during long prints
- **Soldering Iron**: Use proper stand and heat-resistant surface for heat-set insert installation

---

## Print Time Estimates

| Component | STL File | Estimated Print Time | Material Usage |
|---|---|---|---|
| Main Chassis | `body.stl` / `body.3mf` | 8-12 hours | 200-300g |
| Drive Shaft (pair) | `drive_shaft.stl` / `drive_shaft.3mf` | 1-2 hours | 20-30g |
| Motor Mounts (pair) | (Future release) | 2-4 hours | 40-60g |
| Electronic Enclosures | (Future release) | 3-6 hours | 80-120g |

**Total Estimated Material**: 350-530g PETG for complete robot

**Note**: Additional STL files for motor mounts, wheel hubs, and electronic enclosures will be added to `schematic/stl/` in future releases.

---

## References

- Elegoo Centauri Carbon Manual: [Manufacturer Documentation]
- Creality Filament Dryer Settings: [Product Specifications]
- PETG Material Properties: [Material Database]
- Elegoo Slicer Documentation: [Elegoo Support]

---

## Revision History

- 2025-12-29: Initial documentation with PETG prototyping settings
- Future: ABS production settings to be added

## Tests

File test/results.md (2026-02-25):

# Testing

## Node Take Up

```bash
ros2 node list --no-daemon
/driver/driver_container
/driver/motor_controller
/launch_ros_4817
/lifecycle_manager_navigation
root@mazebot:/home/aaron/ros2_ws# ros2 lifecycle nodes
/driver/motor_controller
```

### Check State

```bash
ws# ros2 lifecycle get /driver/motor_controller
unconfigured [1]
```

```bash
root@mazebot:/home/aaron/ros2_ws# ros2 lifecycle set /driver/motor_controller configure
Transitioning successful
```

#### Log Results

```text
[component_container_mt-1] [DEBUG] [1771999544.408227173] [pluginlib.ClassLoader]: Checking path /home/aaron/ros2_ws/install/rr_gpio_pi4b_pigpio_plugin/lib/librr_gpio_pi4b_pigpio_plugin.so 
[component_container_mt-1] [DEBUG] [1771999544.408403343] [pluginlib.ClassLoader]: Library rr_gpio_pi4b_pigpio_plugin found at explicit path /home/aaron/ros2_ws/install/rr_gpio_pi4b_pigpio_plugin/lib/librr_gpio_pi4b_pigpio_plugin.so.
[component_container_mt-1] [DEBUG] [1771999544.432989701] [pluginlib.ClassLoader]: rr_gpio_pi4b_pigpio_plugin::RrGpioPi4BPigpioPlugin maps to real class type rr_gpio_pi4b_pigpio_plugin::RrGpioPi4BPigpioPlugin
[component_container_mt-1] [DEBUG] [1771999544.433137056] [pluginlib.ClassLoader]: std::unique_ptr to object of real type rr_gpio_pi4b_pigpio_plugin::RrGpioPi4BPigpioPlugin created.
[component_container_mt-1] [INFO] [1771999544.434076168] [GPIO_PI4]: configuring GPIO
[component_container_mt-1] [INFO] [1771999544.434581345] [driver.motor_controller]: Configuring motor controller...
[component_container_mt-1] [INFO] [1771999544.434747441] [Motor]: Configuring motor...
[component_container_mt-1] [INFO] [1771999544.435009891] [MotorEncoder]: Configuring encoder...
[component_container_mt-1] [INFO] [1771999544.435073225] [driver.motor_controller]: Configuring motor controller...
[component_container_mt-1] [INFO] [1771999544.435163375] [Motor]: Configuring motor...
[component_container_mt-1] [INFO] [1771999544.435236766] [MotorEncoder]: Configuring encoder...
[component_container_mt-1] [DEBUG] [1771999544.435370213] [rcl]: Sending service response
```

Activate failed:

```text
[component_container_mt-1] [INFO] [1771999544.435236766] [MotorEncoder]: Configuring encoder...
[component_container_mt-1] [DEBUG] [1771999544.435370213] [rcl]: Sending service response
[component_container_mt-1] [DEBUG] [1771999631.932319952] [rcl]: Service server taking service request
[component_container_mt-1] [DEBUG] [1771999631.932450695] [rcl]: Service take request succeeded: true
[component_container_mt-1] [DEBUG] [1771999631.932488714] [rcl]: Sending service response
[component_container_mt-1] [DEBUG] [1771999631.939745019] [rcl]: Service server taking service request
[component_container_mt-1] [DEBUG] [1771999631.939873484] [rcl]: Service take request succeeded: true
[component_container_mt-1] [INFO] [1771999632.069518287] [Motor]: Activating motor...
[component_container_mt-1] [INFO] [1771999632.071337224] [Motor]: Activating motor...
[component_container_mt-1] [ERROR] [1771999632.071550042] [GPIO_PI4]: set_isr_func_ex - PI_BAD_ISR_INIT
[component_container_mt-1] [ERROR] [1771999632.071672656] [MotorEncoder]: could not attach ISR callback to pin 8...
[component_container_mt-1] [INFO] [1771999632.071732731] [Motor]: Deactivating motor...
[component_container_mt-1] [ERROR] [1771999632.071786454] [driver.motor_controller]: Encoder activation failed!!
[component_container_mt-1] [INFO] [1771999632.172069734] [Motor]: Deactivating motor...
[component_container_mt-1] [INFO] [1771999632.172288033] [Motor]: Deactivating motor...
[component_container_mt-1] [FATAL] [1771999632.172375331] [driver.motor_controller]: failed to activate motor(s)
[component_container_mt-1] [DEBUG] [1771999632.200997191] [rcl]: Sending service response
```

This could be caused by incorrect PIGPIO library getting used.

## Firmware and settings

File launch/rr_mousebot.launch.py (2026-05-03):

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
import launch
from launch_ros.actions import ComposableNodeContainer
from launch_ros.descriptions import ComposableNode
from launch_ros.actions import Node
from launch.actions import IncludeLaunchDescription
from launch.launch_description_sources import PythonLaunchDescriptionSource
from ament_index_python.packages import get_package_share_directory
from launch.actions import TimerAction

def generate_launch_description():
    """Launch composable nodes."""

    # GPIO map (BCM numbering)
    # 2,3   — I2C1 SDA/SCL (BNO055)
    # 12,13 — HW PWM0/1 (motor driver)
    # 14,15 — UART TX/RX (LIDAR serial)
    # 17,22 — encoder A/B
    # 23,27 — motor direction
    # 24    — LIDAR 5V MOSFET switch (CE09733), driven high in LIDAR node on_activate

    # Include LDLidar launch
    ldlidar_launch = IncludeLaunchDescription(
        launch_description_source=PythonLaunchDescriptionSource([
            get_package_share_directory('ldlidar_node'),
            '/launch/ldlidar_bringup.launch.py'
        ]),
        launch_arguments={
            'node_name': 'ldlidar_node'
        }.items()
    )

    return launch.LaunchDescription([
        # Include LDLidar bringup (lifecycle node)
        ldlidar_launch,

        # Low level communications, serial, and UDP, or bridges to flight controller.
        ComposableNodeContainer(
            name='driver_container',
            namespace='driver',
            package='rclcpp_components',
            executable='component_container_mt',
            arguments=['--ros-args', '--log-level', 'debug'],
            composable_node_descriptions=[

                ComposableNode(
                    package='rr_motor_controller',
                    plugin='rr_motor_controller::RrECU',
                    name='motor_controller',
                    namespace='driver',
                    parameters=[{
                        'motor_count': 2,
                        'ppr': 8,
                        'wheel_radius': 20,   # 20 mm radius = 40 mm diameter wheels
                        'wheel_base':   70,   # 70 mm between left and right wheel contact points
                        'pwm_freq': 1000,
                        # One pin per motor: index 0 = left, index 1 = right
                        #
                        # Note: for wiring, B represents H-Bridge B and A represents A on H-bridge
                        'encoder_pins': [17, 22],    # LEFT=17 (B), RIGHT=22 (A)
                        'pwm_pins':     [12, 13],    # LEFT=12(HW PWM0 B), RIGHT=13(HW PWM1 A)
                        'dir_pins':     [27, 23],    # LEFT=27 (B), RIGHT=23 (A)
                        'encoder_timeout': 500000,
                        # 'ttl_ns': 500000000,   # 500 ms command TTL — re-enable once validated with fresh batteries
                        # Raspberry Pi 4B GPIO plugin — see https://github.com/Ryder-Robots/rr_gpio_pi4b_pigpio_plugin
                        'transport_plugin': 'rr_gpio_pi4b_pigpio_plugin::RrGpioPi4BPigpioPlugin',
                        # 6×6 row-major pose covariance [x, y, z, roll, pitch, yaw].
                        # Diagonal: x=0.01, y=0.01, z=1e6, roll=1e6, pitch=1e6, yaw=0.01
                        # z, roll, pitch set to 1e6 — not tracked on a flat floor.
                        'covariance': [
                            0.01, 0.0,  0.0,  0.0,  0.0,  0.0,
                            0.0,  0.01, 0.0,  0.0,  0.0,  0.0,
                            0.0,  0.0,  1e6,  0.0,  0.0,  0.0,
                            0.0,  0.0,  0.0,  1e6,  0.0,  0.0,
                            0.0,  0.0,  0.0,  0.0,  1e6,  0.0,
                            0.0,  0.0,  0.0,  0.0,  0.0,  0.01,
                        ],
                    }],
                    extra_arguments=[{'use_intra_process_comms': True}],
                ),

                # Note that this is a lifecycle node within this version
                # ComposableNode(
                #     package='udp_driver',
                #     plugin='drivers::udp_driver::UdpReceiverNode',
                #     namespace='driver',
                #     name='udp_receiver_node',
                #     parameters=[{
                #         "ip": '0.0.0.0',
                #         "port": 57410,
                #     }],
                #     extra_arguments=[{'use_intra_process_comms': True}],
                # ),

                # # Note that this is a lifecycle node within this version
                # ComposableNode(
                #     package='udp_driver',
                #     plugin='drivers::udp_driver::UdpSenderNode',
                #     namespace='driver',
                #     name='udp_sender_node',
                #     parameters=[{
                #         # transport_driver does not natively support
                #         # SO_BROADCAST option, so change IP Address as
                #         # appropriate
                #         "ip": '192.168.1.20',
                #         "port": 57410,
                #     }],
                #     extra_arguments=[{'use_intra_process_comms': True}],
                # ),
            ],
        ),
        Node(
            package='rr_bosch_lc_base',
            executable='rr_bosch_sensor_main',
            namespace='sensors',
            output='screen',
            arguments=['--ns', 'sensors'],
            parameters=[{
                'requires_calibration': False,
            }],
        ),
        TimerAction(
            period=3.0,
            actions=[
            Node(
                package='nav2_lifecycle_manager',
                executable='lifecycle_manager',
                name='lifecycle_manager_navigation',
                output='screen',
                parameters=[{
                    'autostart': True,
                    'bond_timeout': 15.0,
                    'node_names': [
                        'ldlidar_node',
                        '/sensors/rr_bosch_imu_node',
                        '/driver/motor_controller',
                    ]
                }],
            ),
            ]
        )
    ])

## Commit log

2025-12-13 fixed plugin issue within launch script
    [rr_mousebot.launch.py]
2025-12-13 fixed incorrect node reference
    [rr_mousebot.launch.py]
2025-12-26 added basic body design
    [body.FCStd, hexwheel.FCStd, mazebot.FCStd]
2025-12-27 added firther schematic overview files
    [battery_pack.FCStd, buck_circuit.FCStd, caster_wheel.FCStd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]
2025-12-28 add base designs
    [Raspberry Pi 4 Model B.STEP.FCStd, body.FCStd, tt_motor.FCStd]
2025-12-28 added scheamtics
    [body.FCStd]
2025-12-28 Updated BOM
2025-12-29 updated documentation
    [body.FCStd]
2025-12-29 added wheel selection
2025-12-29 added CONTRUCTION guide
    [body.FCStd, body.stl]
2025-12-29 added developer notes
    [body.3mf, body.FCStd]
2025-12-30 updated body, started drive shaft
    [body.FCStd, body.stl, drive_shaft.FCStd]
2025-12-30 added drive shaft STL
    [body.3mf, drive_shaft.3mf, drive_shaft.FCStd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]
2026-01-02 case updates
    [body.3mf, body.FCStd, body.stl]
2026-01-04 updates to battery
2026-01-04 updated BOM and other information
2026-01-05 added motor encoder mounts, and holes for regulator
    [body.3mf, body.FCStd, body.stl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]
2026-01-06 Updated BOM: replaced mecanum wheels with 65mm rubber tire wheels, updated chassis STL files
    Changes:
    - Replaced mecanum wheels (FIT0653/FIT0654) with Sparkfun 65mm rubber tire pair (ROB-13259)
    - Simplified to differential drive configuration
    - Updated total component cost from ~$485 to ~$476 AUD
    - Removed mecanum wheel placement instructions from assembly notes
    - Updated component selection rationale for rubber tire wheels
    - Updated body.stl and body.3mf to reflect design changes
    - Removed drive_shaft STL files (no longer needed)
    [body.3mf, body.stl, drive_shaft.3mf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]
2026-01-06 added counter bore casing
    [body.3mf, body.FCStd, body.stl]
2026-01-08 redesign of main body
    [body.3mf, body.FCStd]
2026-01-08 fixed miss-placed artefacts
    [body.3mf, body.FCStd]
2026-01-08 snapshot of body, before next change
    [body.FCStd]
2026-01-11 added stand offs
    [body.3mf, body.FCStd, body.stl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]
2026-01-11 Added motor connection instructions
2026-01-15 added motor encoder
2026-01-19 more configuration for LIDAR
2026-01-21 need to fix sensor node, but most other components seem to be working.
    [rr_mousebot.launch.py]
2026-01-22 added new documenation for motors
2026-02-24 modified launch config to suite modified motor controller
2026-02-25 adding motor controller to configuration
2026-02-25 updated script for motor controller
2026-02-25 attempting to fix bad firing issue
    [rr_mousebot.launch.py]
2026-02-25 added timer action to stop lifecycle manager from exiting before node has registered.
2026-03-02 Updated launch file to match new non conflictinmg wiring.
2026-03-04 addded comments to explain mousebot pin diagram
2026-03-09 updated documenation and design
    [body.3mf, body.FCStd]
2026-03-28 added IMU device
2026-04-03 re-enabled motor controller
2026-04-05 updated packages, added lidar to launch
2026-05-14 added circuit diagram for lidar
